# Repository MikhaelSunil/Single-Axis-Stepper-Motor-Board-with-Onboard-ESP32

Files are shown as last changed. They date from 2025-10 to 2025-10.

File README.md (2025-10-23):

# 🧭 SINGLE-AXIS STEPPER MOTOR CONTROLLER BOARD WITH ESP32

This project is a **compact single-axis stepper motor controller board** centered on an **ESP32 microcontroller** and an integrated **DRV8825 stepper motor driver**.  
The board accepts a 12 V motor supply, provides regulated 5 V and 3.3 V outputs, supports mechanical limit switches for homing and end-stop safety, and enables both **Wi-Fi** and **Bluetooth** remote control.

---
**
**
## 🎯 OBJECTIVE
To develop a **modular, intelligent, single-axis motion control board** that integrates an **ESP32** microcontroller and **DRV8825** stepper driver with built-in **limit switch** support — suitable for automation and robotics applications.

---

## ⚙️ DESIGN OVERVIEW
The board integrates three main subsystems:

1. **Microcontroller Unit (ESP32-DevkitC)**  
   Handles motor control and limit switch detection.
2. **Power Regulation System**  
   Uses dual **LM2596** buck converters for 12 V → 5 V and 3.3 V rails.
3. **Motor Driver Subsystem (DRV8825)**  
   Provides microstepping control, efficient current regulation, and protection features.

---


## 🧠 MICROCONTROLLER – ESP32 DEVKITC
The **ESP32** was selected over alternatives like the **STM32**, **SAMD**, and **RP2040** for its:
- Superior processing power  
- Integrated **Wi-Fi** and **Bluetooth**  
- Wide GPIO accessibility  
- Compatibility with STEP/DIR motor control interfaces  

---

## ⚡ STEPPER MOTOR DRIVER – DRV8825
**Texas Instruments DRV8825** offers key advantages:
- **Wide Voltage Range:** 8.2 V – 45 V  
- **High Current:** Up to 2.2 A per phase  
- **Microstepping:** Up to 1/32 steps for fine resolution  
- **Built-in Protections:** Over-temperature, over-current, and short-to-ground  
- **Ease of Control:** Simple STEP/DIR interface  

---

## 🔩 STEP-SIZE SELECTION FEATURE
The board provides **microstep selection jumpers**, allowing dynamic configuration from **full-step to 1/32-step** without changing the software — ideal for performance and precision tuning.

---

## 🔋 POWER SUPPLY DESIGN

### **Input**
- 12 V DC main supply (motor and logic source)

### **Regulated Outputs**
- **LM2596T (5 V Output)** – High-efficiency regulator (>80%), powers peripherals and logic.  
- **LM2596S (3.3 V Output)** – Dedicated rail for step-selection jumpers and pull-ups with LC filtering.

---

## 🏁 LIMIT SWITCH AND HOMING INTEGRATION
Includes two **mechanical limit switches** with pull-up resistors for reliable **homing** and **end-stop** detection.  
Applications include **CNC**, **linear actuators**, and **positioning systems**.

---

## 🧾 PINOUT DESCRIPTION

| Signal | ESP32 GPIO | I/O | Connected Component | Description |
|---|---|---|---|---|
| **DIR_PIN**  | GPIO 19 | Output  | DRV8825 DIR | Motor rotation direction (HIGH = Forward, LOW = Reverse) |
| **STEP_PIN** | GPIO 18 | Output  | DRV8825 STEP | Step pulse signal for motor movement |
| **EN_PIN** | GPIO 21 | Output  | DRV8825 ENABLE | Active LOW enable/disable for driver output |
| **LIMIT_MIN**| GPIO 32 | Input | Mechanical Limit Switch (Home) | Detects home position (LOW = Pressed) |
| **LIMIT_MAX**| GPIO 33 | Input | Mechanical Limit Switch (End)  | Detects maximum travel (LOW = Pressed) |

---

## 💡 NOVELTY & KEY FEATURES
- **Unified Architecture:** ESP32 + DRV8825 + Power Regulation on a single PCB  
- **Full GPIO Access:** Enables sensor, relay, and IoT expansion  
- **Dual Power Path:** Independent LM2596 converters reduce EMI  
- **OTA Upgradability:** Firmware updates over Wi-Fi  
- **Scalable Design:** Multiple boards networked for multi-axis systems  

---

## 🚀 APPLICATIONS
- 🧰 **CNC Machines & 3D Printers** – Precision motion control with homing  
- 🤖 **Autonomous Robotics** – For actuators, camera sliders, robot joints  
- 🌐 **IoT Mechatronics Systems** – Wi-Fi/BLE remote stepper control  
- ⚗️ **Smart Automation & Lab Equipment** – Syringe pumps, optical stages  
- 🎓 **Educational / Research Prototyping** – Open, reconfigurable motion control platform  

---

## 🧩 LICENSE
This project is open-source under the **MIT License**.  
You are free to use, modify, and distribute it with attribution.

---

## 👨‍🔧 Author
**Mikhael Sunil**  
Embedded Systems & Robotics Engineer  
📧 [LinkedIn](https://www.linkedin.com/in/mikhaelsunil) • 🌐 [GitHub](https://github.com/mikhaelsunil)

---

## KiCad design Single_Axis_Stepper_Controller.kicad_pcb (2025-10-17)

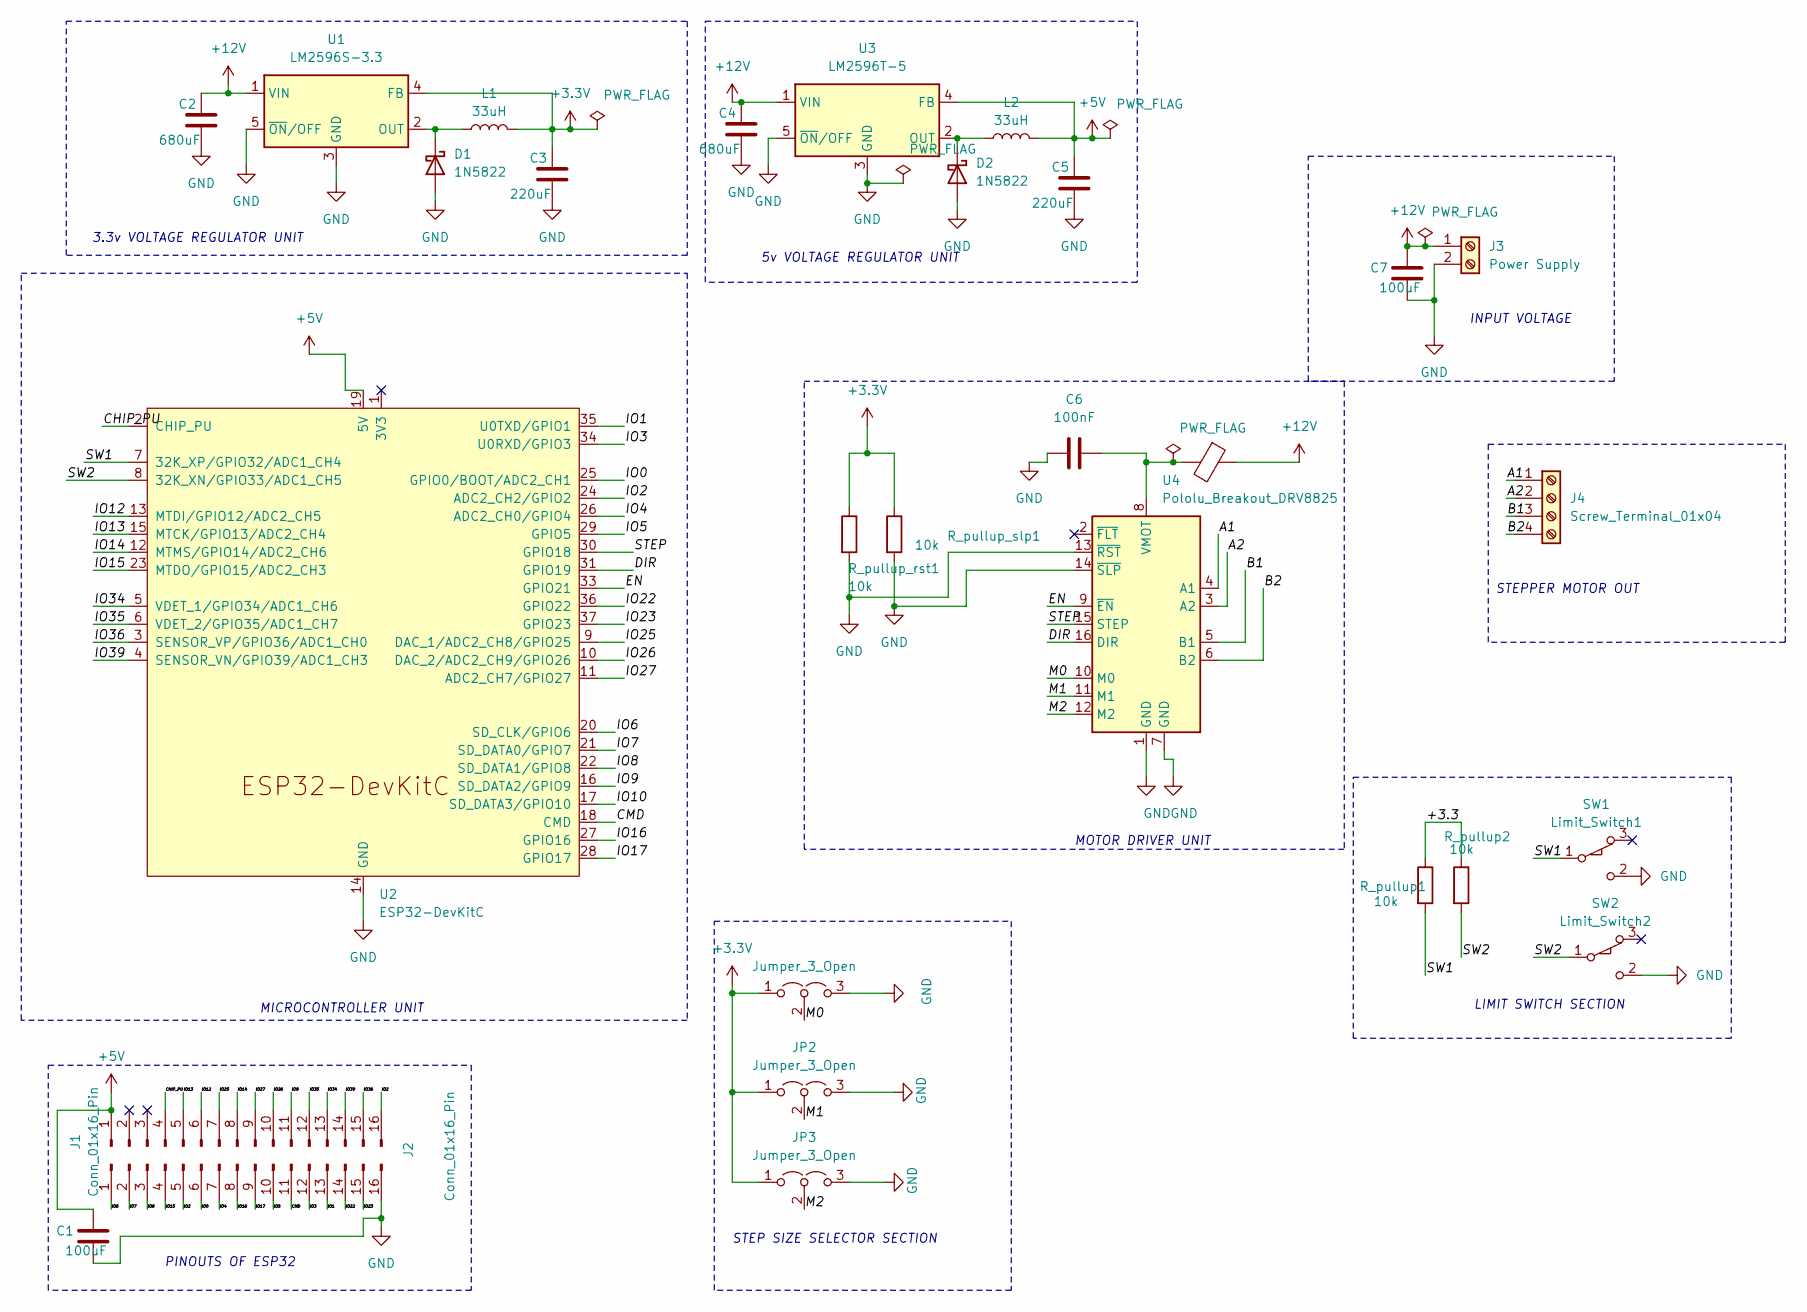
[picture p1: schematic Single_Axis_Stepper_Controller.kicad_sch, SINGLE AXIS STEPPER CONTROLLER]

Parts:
C1: 100uF; CP_Radial_D6.3mm_P2.50mm
C2, C4: 680uF; CP_Radial_D18.0mm_P7.50mm
C3: 220uF; CP_Radial_D18.0mm_P7.50mm
C5: 220uF; CP_Radial_D12.5mm_P2.50mm
C6: 100nF; CP_Radial_D7.5mm_P2.50mm
C7: 100uF; CP_Radial_D12.5mm_P5.00mm
D1, D2: 1N5822; D_DO-201AD_P15.24mm_Horizontal
FB1: FerriteBead; LairdTech_28C0236-0JW-10
J1, J2: Conn_01x16_Pin; PinHeader_1x16_P2.54mm_Vertical
J3: Power Supply; TerminalBlock_MaiXu_MX126-5.0-02P_1x02_P5.00mm
J4: Screw_Terminal_01x04; TerminalBlock_MaiXu_MX126-5.0-04P_1x04_P5.00mm
JP1, JP2, JP3: Jumper_3_Open; SolderJumper-3_P1.3mm_Open_Pad1.0x1.5mm
L1, L2: 33uH; L_Axial_L5.0mm_D3.6mm_P10.00mm_Horizontal_Murata_BL01RN1A2A2
R_pullup1, R_pullup2: 10k; R_Axial_DIN0207_L6.3mm_D2.5mm_P15.24mm_Horizontal
R_pullup_rst1: 10k; R_Axial_DIN0207_L6.3mm_D2.5mm_P15.24mm_Horizontal
R_pullup_slp1: 10k; R_Axial_DIN0207_L6.3mm_D2.5mm_P15.24mm_Horizontal
SW1: Limit_Switch1; SW_XKB_DM1-16UP-1
SW2: Limit_Switch2; SW_XKB_DM1-16UP-1
U1: LM2596S-3.3; TO-263-5_TabPin3
U2: ESP32-DevKitC
U3: LM2596T-5; TO-220-5_P3.4x3.7mm_StaggerOdd_Lead3.8mm_Vertical
U4: Pololu_Breakout_DRV8825; Pololu_Breakout-16_15.2x20.3mm

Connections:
+3.3V: C3.1, JP1.1 (A), JP2.1 (A), JP3.1 (A), L1.2, R_pullup_rst1.1, R_pullup_slp1.1, U1.4 (FB)
+5V: C1.1, C5.1, J1.1, L2.2, U2.19 (5V), U3.4 (FB)
+12V: C2.1, C4.1, C7.1, FB1.1, J3.1, U1.1 (VIN), U3.1 (VIN)
/+3.3: R_pullup1.1, R_pullup2.1
/A1: J4.1, U4.4 (A1)
/A2: J4.2, U4.3 (A2)
/B1: J4.3, U4.5 (B1)
/B2: J4.4, U4.6 (B2)
/CHIP_PU: J1.4, U2.2 (CHIP_PU)
/CMD: J2.11, U2.18 (CMD)
/DIR: U2.31 (GPIO19), U4.16 (DIR)
/EN: U2.33 (GPIO21), U4.9 (~EN)
/IO0: J2.6, U2.25 (GPIO0/BOOT/ADC2_CH1)
/IO1: J2.13, U2.35 (U0TXD/GPIO1)
/IO2: J1.16, J2.5, U2.24 (ADC2_CH2/GPIO2)
/IO3: J2.12, U2.34 (U0RXD/GPIO3)
/IO4: J2.7, U2.26 (ADC2_CH0/GPIO4)
/IO5: J2.10, U2.29 (GPIO5)
/IO6: J2.1, U2.20 (SD_CLK/GPIO6)
/IO7: J2.2, U2.21 (SD_DATA0/GPIO7)
/IO8: J2.3, U2.22 (SD_DATA1/GPIO8)
/IO9: J1.11, U2.16 (SD_DATA2/GPIO9)
/IO10: U2.17 (SD_DATA3/GPIO10)
/IO12: J1.6, U2.13 (MTDI/GPIO12/ADC2_CH5)
/IO13: J1.5, U2.15 (MTCK/GPIO13/ADC2_CH4)
/IO14: J1.8, U2.12 (MTMS/GPIO14/ADC2_CH6)
/IO15: J2.4, U2.23 (MTDO/GPIO15/ADC2_CH3)
/IO16: J2.8, U2.27 (GPIO16)
/IO17: J2.9, U2.28 (GPIO17)
/IO22: J2.14, U2.36 (GPIO22)
/IO23: J2.15, U2.37 (GPIO23)
/IO25: J1.7, U2.9 (DAC_1/ADC2_CH8/GPIO25)
/IO26: J1.10, U2.10 (DAC_2/ADC2_CH9/GPIO26)
/IO27: J1.9, U2.11 (ADC2_CH7/GPIO27)
/IO34: J1.13, U2.5 (VDET_1/GPIO34/ADC1_CH6)
/IO35: J1.12, U2.6 (VDET_2/GPIO35/ADC1_CH7)
/IO36: J1.15, U2.3 (SENSOR_VP/GPIO36/ADC1_CH0)
/IO39: J1.14, U2.4 (SENSOR_VN/GPIO39/ADC1_CH3)
/M0: JP1.2 (C), U4.10 (M0)
/M1: JP2.2 (C), U4.11 (M1)
/M2: JP3.2 (C), U4.12 (M2)
/STEP: U2.30 (GPIO18), U4.15 (STEP)
/SW1: R_pullup1.2, SW1.1 (A), U2.7 (32K_XP/GPIO32/ADC1_CH4)
/SW2: R_pullup2.2, SW2.1 (A), U2.8 (32K_XN/GPIO33/ADC1_CH5)
GND: C1.2, C2.2, C3.2, C4.2, C5.2, C6.2, C7.2, D1.2 (A), D2.2 (A), J2.16, J3.2, JP1.3 (B), JP2.3 (B), JP3.3 (B), R_pullup_rst1.2, R_pullup_slp1.2, SW1.2 (B), SW2.2 (B), U1.3 (GND), U1.5 (~ON/OFF), U2.14 (GND), U2.32 (GND), U2.38 (GND), U3.3 (GND), U3.5 (~ON/OFF), U4.1 (GND), U4.7 (GND), U4.13 (~RST), U4.14 (~SLP)
unnamed: D1.1 (K), L1.1, U1.2 (OUT)
unnamed: D2.1 (K), L2.1, U3.2 (OUT)
unnamed: C6.1, FB1.2, U4.8 (VMOT)

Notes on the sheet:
MICROCONTROLLER UNIT
STEPPER MOTOR OUT
3.3v VOLTAGE REGULATOR UNIT
LIMIT SWITCH SECTION
PINOUTS OF ESP32
5v VOLTAGE REGULATOR UNIT
STEP SIZE SELECTOR SECTION
MOTOR DRIVER UNIT
INPUT VOLTAGE

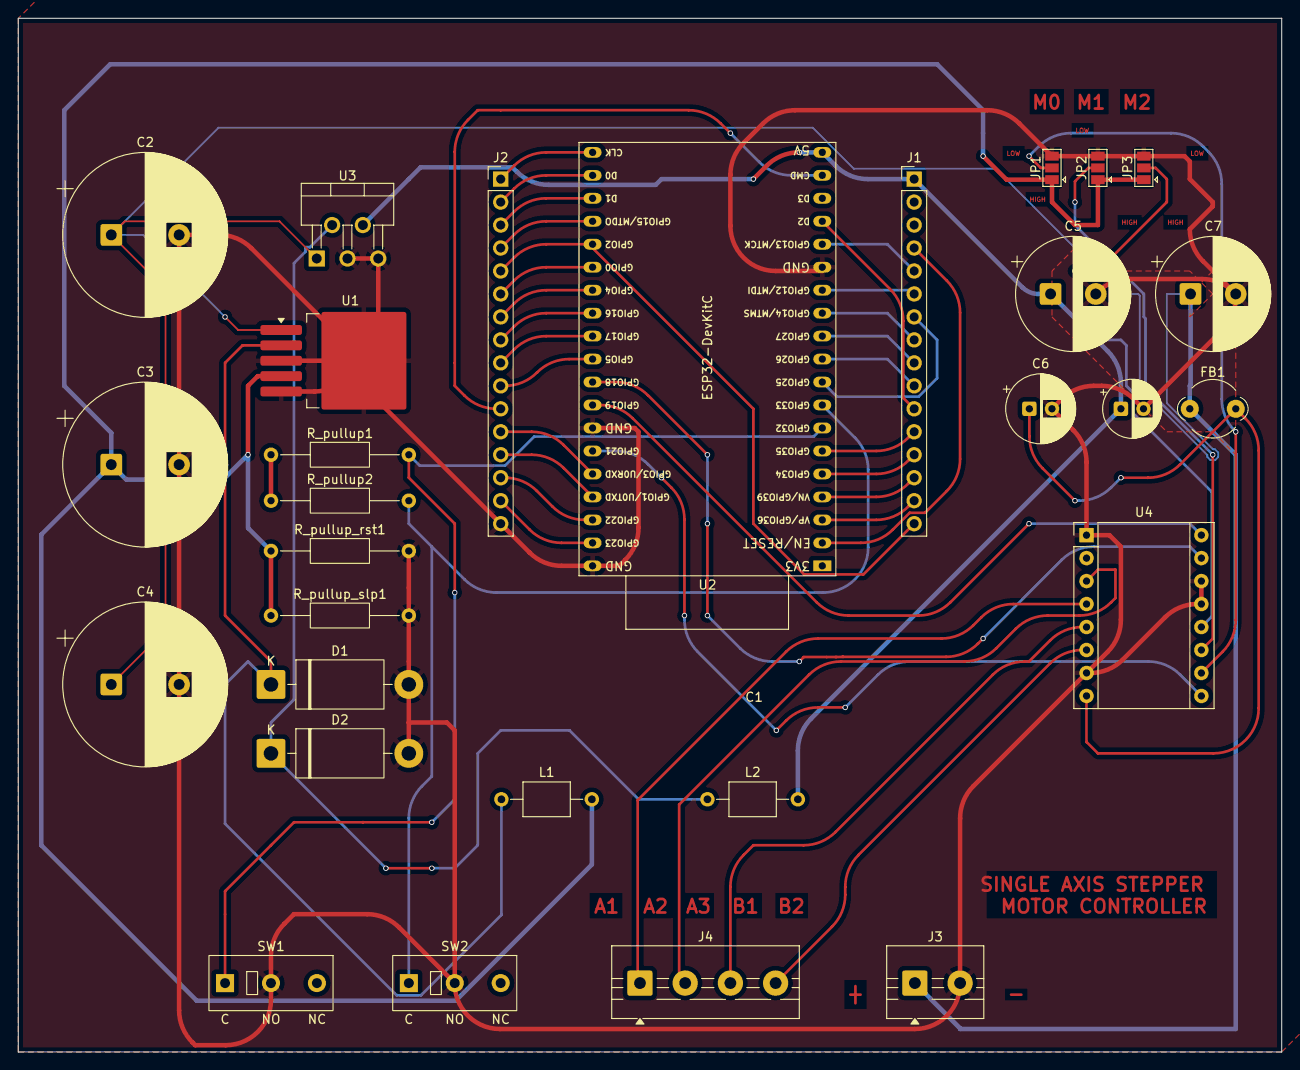
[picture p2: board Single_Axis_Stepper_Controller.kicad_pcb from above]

Board: 2 copper layers, 139.7 x 114.3 mm, 29 parts (0 on the bottom side), 47 nets.

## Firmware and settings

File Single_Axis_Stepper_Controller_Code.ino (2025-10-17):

// Single-axis stepper controller with homing 
#define DIR_PIN      19   // Direction
#define STEP_PIN     18   //  Step
#define EN_PIN       21   //  Enable 
#define LIMIT_MIN    32   // Limit switch for Home 
#define LIMIT_MAX    33   // Limit switch for End 


const int stepsPerRevolution = 200; // Full steps per revolution (1.8° motor)(aprrox estimation)
const int microstepSetting   = 16;      // 16 for 1/16 microstepping
const int stepDelay          = 800;     // Microseconds between steps (~speed)

void setup() {
  Serial.begin(115200);

  pinMode(DIR_PIN, OUTPUT);
  pinMode(STEP_PIN, OUTPUT);
  pinMode(EN_PIN, OUTPUT);
  pinMode(LIMIT_MIN, INPUT_PULLUP);
  pinMode(LIMIT_MAX, INPUT_PULLUP);

  digitalWrite(EN_PIN, LOW);  
  Serial.println("System Initialized. Starting homing sequence...");

  homeAxis();
}

void loop() {
  
  moveToLimit(LIMIT_MAX, true);   // Move toward max limit
  delay(1000);
  moveToLimit(LIMIT_MIN, false);  // Move toward min limit
  delay(1000);
}

void homeAxis() {
  digitalWrite(DIR_PIN, LOW); // Move toward home (negative)
  Serial.println("Homing...");

  while (digitalRead(LIMIT_MIN) == HIGH) {
    stepMotor();
  }

  Serial.println("Home position reached.");
  delay(200);
  // Back off slightly from the limit switch
  digitalWrite(DIR_PIN, HIGH);
  for (int i = 0; i < 100; i++) stepMotor();

  Serial.println("Axis homed and ready.");
}


void moveToLimit(int limitPin, bool dirForward) {
  digitalWrite(DIR_PIN, dirForward ? HIGH : LOW);
  Serial.print("Moving ");
  Serial.print(dirForward ? "forward" : "backward");
  Serial.print(" until limit pin ");
  Serial.print(limitPin);
  Serial.println("...");


  while (digitalRead(limitPin) == HIGH) {
    // If opposite limit triggers accidentally, stop
    if (!dirForward && digitalRead(LIMIT_MIN) == LOW) break;
    if (dirForward && digitalRead(LIMIT_MAX) == LOW) break;

    stepMotor();
  }

  Serial.println("Limit reached, motion stopped.");
}

void stepMotor() {
  digitalWrite(STEP_PIN, HIGH);
  delayMicroseconds(stepDelay);
  digitalWrite(STEP_PIN, LOW);
  delayMicroseconds(stepDelay);
}

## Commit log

2025-10-17 Initial commit - added KiCad project and controller code
    [Single_Axis_Stepper_Controller.kicad_pcb, Single_Axis_Stepper_Controller.kicad_sch]
2025-10-23 Revise README for single-axis stepper motor controller
    Updated README to enhance project description and features.
